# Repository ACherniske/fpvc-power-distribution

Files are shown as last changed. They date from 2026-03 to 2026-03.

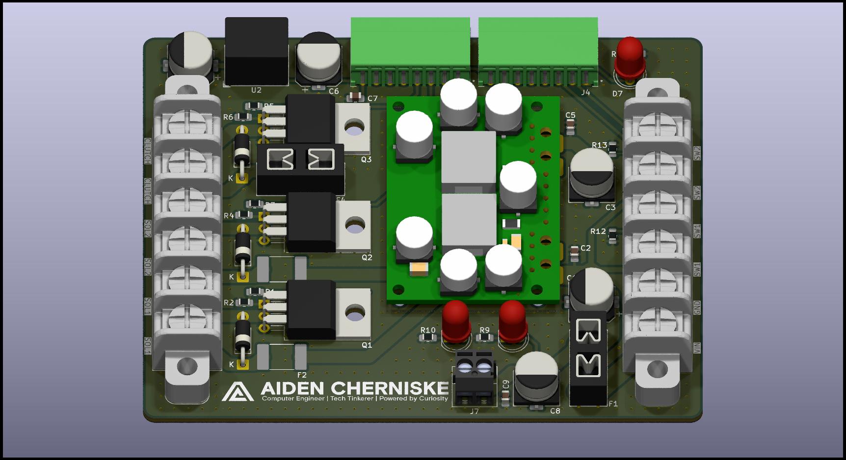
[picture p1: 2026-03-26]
images/fpvc-power-distribution.jpg

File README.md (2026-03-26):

# FPVC Power Distribution Board







A 2-layer power distribution board designed in KiCad for the NFPA Fluid Powered Vehicle Challenge. Handles input fusing, load switching via MOSFETs, and regulated 5V/12V/24V outputs.

---

## Board Images

### Top and bottom layers

| Top layer | Bottom layer |
|---|---|
| FPVC power distribution board top layer | FPVC power distribution board bottom layer |

### Schematic

FPVC power distribution board overview

---

## Ordering from JLCPCB

### 1. Download the Gerber files

Download the latest Gerber files from the [Releases](../../releases) page as a `.zip` file. Do not unzip it — JLCPCB accepts the zip directly.

### 2. Upload to JLCPCB

1. Go to [jlcpcb.com](https://jlcpcb.com) and click **Order Now**
2. Click **Add Gerber File** and upload the `.zip`
3. JLCPCB will render a preview of the board — verify it looks correct before continuing

### 3. Configure the order options

Once uploaded, a list of fabrication options will appear. Set them as follows:

| Option | Value | Notes |
|---|---|---|
| **Base Material** | FR-4 | Standard PCB material |
| **Layers** | 2 | |
| **Dimensions** | Auto-detected | Verify against preview |
| **PCB Qty** | 5 (minimum) | Adjust as needed |
| **PCB Thickness** | 1.6mm | Standard |
| **PCB Color** | Your choice | Green is cheapest/fastest |
| **Silkscreen** | White | |
| **Surface Finish** | HASL (with lead) | Lead-free HASL also fine |
| **⚠️ Outer Copper Weight** | **2oz** | **Critical — must change from default** |
| **Via Covering** | Tented | |
| **Board Outline Tolerance** | ±0.2mm | Standard |
| **Confirm Production File** | No | |
| **Remove Order Number** | No | Yes adds ~$1.50 |

> **Why 2oz copper?** This board carries significant DC load currents through its power traces. 2oz copper (70µm) doubles the trace cross-sectional area compared to the default 1oz, reducing resistance and heat buildup. **Do not order with 1oz copper.**

### 4. Shipping & checkout

1. Click **Save to Cart**
2. Select your shipping method — **DHL Express** or **FedEx** typically arrive in 5–7 days to the US. Economy options are cheaper but can take 3–5 weeks
3. Complete checkout and pay

JLCPCB will send an email when the order moves to production and again when it ships.

---

## Bill of Materials

See [`fpvc-power-distribution-BOM.xlsx`](./documentation/fpvc-power-distribution-BOM.xlsx) for the full BOM. There is a mix of through-hole and surface-mount components. The 0805 package is hand-solderable or can be reflowed.

DigiKey links are provided in the BOM for all components that cannot be found in the Bucknell Maker-E Makerstock.

---

## License

Copyright 2026 Aiden Cherniske

Licensed under the Apache License, Version 2.0. See [`LICENSE`](./LICENSE) for the full text.

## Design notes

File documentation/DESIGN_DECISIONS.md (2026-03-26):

# PCB Design Decisions & Rationale

> Power distribution board designed for the Fluid Powered Vehicle Challenge Senior Design project at Bucknell Unviersity. PCB interfaces with the Velocio Ace PLC to enable the powering and switching of essential bike systems.

---

## Contents

- [Copper Weight](#copper-weight)
- [Trace Width Safety Margins](#trace-width-safety-margins)
- [Ground Planes](#ground-planes)
- [Via Sizing & Parallelism](#via-sizing--parallelism)
- [2-Layer vs 4-Layer](#2-layer-vs-4-layer)

---

## Copper Weight

**Decision:** 2oz copper (70µm) throughout both layers.

2oz was chosen over the standard 1oz, providing roughly double the current carrying capacity per unit trace width. This allows narrower traces for the same current rating and is particularly important for the high current 24V input and clutch circuits, where 1oz copper would require impractically wide traces.

---
 
## Trace Width Safety Margins
 
**Decision:** ~50% margin added over IPC-2221 calculated minimums.
 
All trace widths were calculated using the IPC-2221 standard with the following assumptions:
 
| Parameter | Value |
|---|---|
| Copper weight | 2oz |
| Max temperature rise | 20°C |
| Worst case ambient | 50°C |
| Max conductor temperature | 70°C |
 
The 50% margin accounts for manufacturing variation, hot spots at vias and corners, and transient currents from inductive switching.
 
| Net | IPC-2221 minimum | Routed width |
|-----|---|---|
| Signal / gate drive | 0.1mm | 0.2mm |
| +5V rail | 0.2mm | 0.5mm |
| +12V solenoids (4A total) | 0.6mm | 1.0mm |
| +12V clutch (8A) | 1.8mm | 2.5mm |
| 24V input (15A) | 3.5mm | 4.0mm |

---
 
## Ground Planes
 
**Decision:** GND pours are used on both top and bottom layers.
 
Rather than routing individual signal returns, both copper layers include ground pours tied to the same GND net. This provides low-impedance return paths near active routing on each layer, minimises loop area, and improves current sharing for high-current returns (clutch and solenoid circuits) without requiring oversized dedicated return traces.
 
Stitching vias are used to tie the two GND pours together and prevent isolated copper islands. They are arranged in a 2.54mm grid for regular stitching in open copper regions.

---
 
## Via Sizing & Parallelism
 
**Decision:** Vias are sized by function, with multiple vias in parallel for power nets and a dedicated stitching-via setup for GND pours.
 
Rather than a single standard via size, three classes are used:
 
| Via type | Drill | Finished diameter | Parallelism |
|---|---|---|---|
| Signal | 0.3mm | 0.7mm | Single |
| Power (5V, 12V) | 0.4mm | 0.8mm | 2–3 in parallel |
| High current (24V, clutch) | 0.6mm | 1.2mm | 4–6 in parallel |
| GND stitching | 0.3mm | 0.6mm | 2.54mm grid + additional vias at edges and return-layer transitions |
 
Parallel vias distribute current across multiple paths and provide redundancy against manufacturing defects in any single via.

For GND stitching, KiCad fill-area settings are 0.6mm via diameter, 0.3mm drill, 0.2mm clearance, and 2.54mm grid spacing.

---
 
## Decoupling Capacitor Placement
 
**Decision:** Two-stage decoupling per rail, with strict placement order.
 
Each power rail uses two capacitors placed in sequence along the power trace:
 
```
Connector → 100µF electrolytic → 100nF ceramic → IC power pin
```

- The **100nF ceramic** is placed as close as physically possible to the IC power pin to suppress high frequency noise. Its GND via is placed directly at the pad — not routed to a distant ground point.
- The **100µF electrolytic** is placed further back as a bulk charge reservoir for low frequency ripple.

---
 
## Fuse Strategy
 
**Decision:** SMD polyfuses for low current circuits, Mini blade fuses for high current circuits.
 
| Circuit | Fuse type | Reason |
|---|---|---|
| Solenoids (2A each) | SMD polyfuse, 2920 package | Self-resetting, appropriate for low current inductive loads |
| Clutch (7.5A) | Mini blade, PCB-mount holder | Polyfuses impractical at this current level |
| 24V input (15A) | Mini blade, PCB-mount holder | Polyfuses impractical at this current level |
 
At 7A and above, polyfuses have high hold resistance causing significant voltage drop, are difficult to source, and are expensive. Mini blade fuses are universally available at any automotive supplier, making field replacement straightforward without specialist parts.

---

## 2-Layer vs 4-Layer
 
**Decision:** 2-layer board.
 
The signal frequencies in this design are very low — PLC digital I/O, MOSFET switching for solenoids and a clutch, and DC power regulation. There are no high frequency switching converters, differential signal pairs, or RF circuits that would benefit from the additional ground plane isolation that 4-layer construction provides.
 
4-layer construction often increases PCB fabrication cost. If EMI issues are identified during testing, a 4-layer revision would be straightforward, but this is not anticipated given the low frequency nature of the design.

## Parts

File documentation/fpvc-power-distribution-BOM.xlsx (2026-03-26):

FPVC Power Distribution — Bill of Materials
Qty | Designator | Val | Footprint | Link
5 | R2,R13,R4,R12,R6 | 10k | R_0805_2012Metric_Pad1.20x1.40mm_HandSolder | Maker-E Components
3 | D3,D1,D2 | 1N5819 | D_DO-41_SOD81_P10.16mm_Horizontal | https://www.digikey.com/en/products/detail/stmicroelectronics/1N5819/1865421
2 | F1, F4 | Various | Fuseholder_Blade_Mini_Keystone_3568 | https://www.digikey.com/en/products/detail/keystone-electronics/3568/2137306
1 | F1 | 15A | Mini Blade Fuse | https://www.digikey.com/en/products/detail/littelfuse-inc/0MIN015-VP/3426493
1 | F4 | 7.5A | Mini Blade Fuse | https://www.digikey.com/en/products/detail/littelfuse-inc/029707-5WXNV/146586
5 | C4,C6,C3,C1,C8 | 100uF | CP_Elec_8x6.2 | https://www.digikey.com/en/products/detail/vishay-beyschlag-draloric-bc-components/MAL215097011E3/5635404
3 | Q3,Q1,Q2 | IRLB8314 | TO-220-3_Horizontal_TabDown | https://stock.maker.bucknell.edu/product/nmos-through-hole-3-3v-gate/
4 | C5,C2,C9,C7 | 0.1uF | C_0805_2012Metric_Pad1.18x1.45mm_HandSolder | Maker-E Components
1 | R9 | 2.2k | R_0805_2012Metric_Pad1.20x1.40mm_HandSolder | Maker-E Components
3 | D5, D6, D7 | Various | LED_D5.0mm | https://stock.maker.bucknell.edu/product/led-red-2/
3 | R3,R5,R1 | 220 | R_0805_2012Metric_Pad1.20x1.40mm_HandSolder | Maker-E Components
1 | R11 | 200 | R_0805_2012Metric_Pad1.20x1.40mm_HandSolder | Maker-E Components
2 | F3,F2 | 2A Polyfuse | Fuse_2920_7451Metric_Pad2.10x5.45mm_HandSolder | https://www.digikey.com/en/products/detail/bourns-inc/MF-LSMF200-24X-2/16053096
1 | R10 | 1k | R_0805_2012Metric_Pad1.20x1.40mm_HandSolder | Maker-E Components
1 | U2 | R-78K 5.0-1.0 | Converter_DCDC_RECOM_R-78E-0.5_THT | https://stock.maker.bucknell.edu/product/dc-dc-converter-5-v-1-a/
1 | J7 | Vout_Screen | TerminalBlock_4Ucon_1x02_P3.50mm_Vertical | https://stock.maker.bucknell.edu/product/terminal-blocks-2/
2 | J4, J5 | Various | PHOENIX_1881503 | https://www.digikey.com/en/products/detail/phoenix-contact/1881503/308252
2 | J4, J5 | Various | PHOENIX_1881383 | https://www.digikey.com/en/products/detail/phoenix-contact/1881383/308241
2 | J9, J10 | Various | 8.26mm Pitch Beau PCB Terminal Strip | https://www.digikey.in/en/products/detail/molex/0387006106/3315660

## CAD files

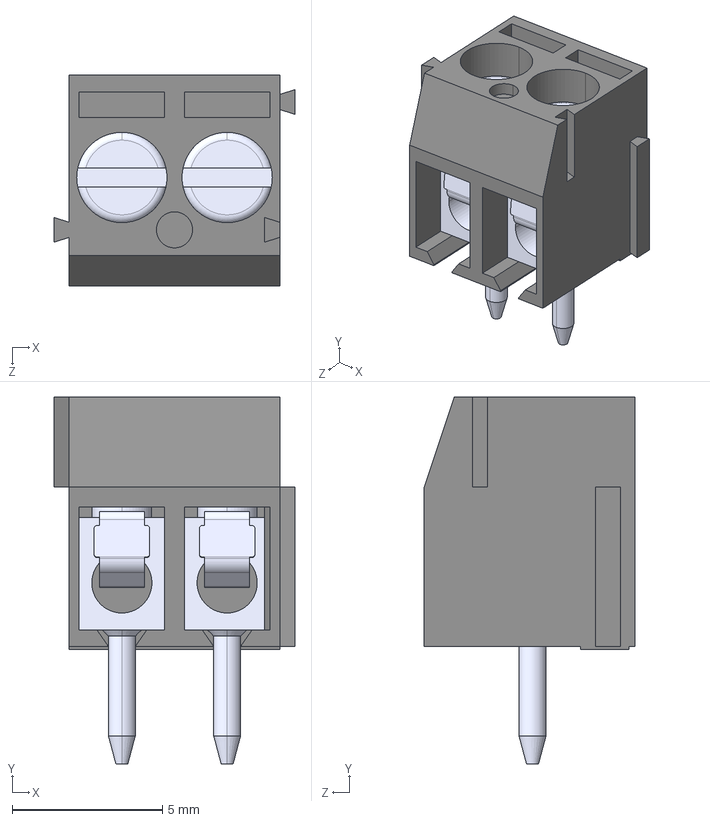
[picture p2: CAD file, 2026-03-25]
kicad/models/OSTTE020104.STEP
8.00 x 12.2 x 7.00 mm

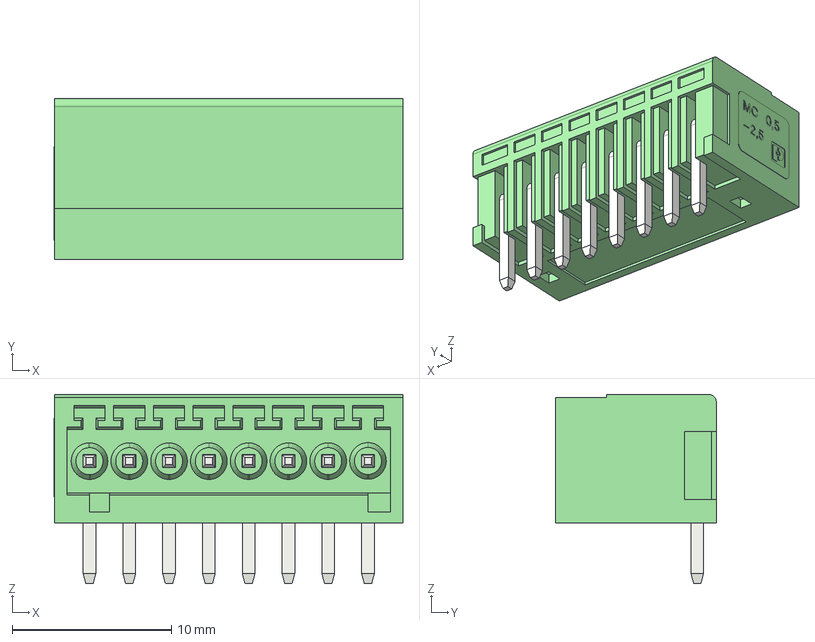
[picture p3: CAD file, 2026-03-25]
kicad/models/pxc_1881503_00_02_MC-0-5-8-G-2-5_3D.stp
21.9 x 10.1 x 11.9 mm

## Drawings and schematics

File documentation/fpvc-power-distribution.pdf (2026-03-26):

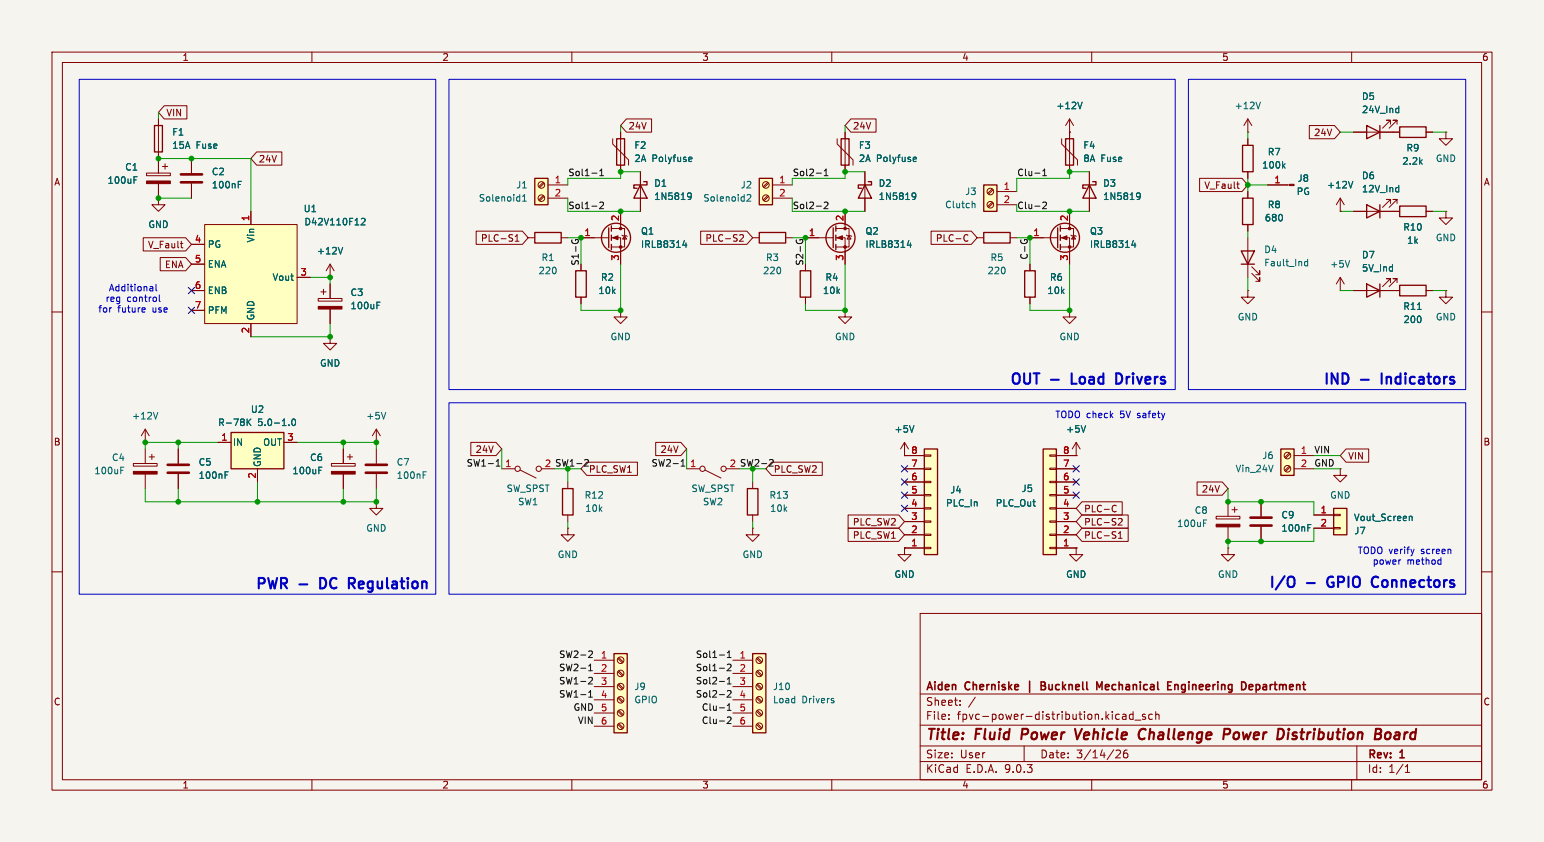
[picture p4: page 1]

Additional reg control for future use

Id: 1/1 Title: Fluid Power Vehicle Challenge Power Distribution Board

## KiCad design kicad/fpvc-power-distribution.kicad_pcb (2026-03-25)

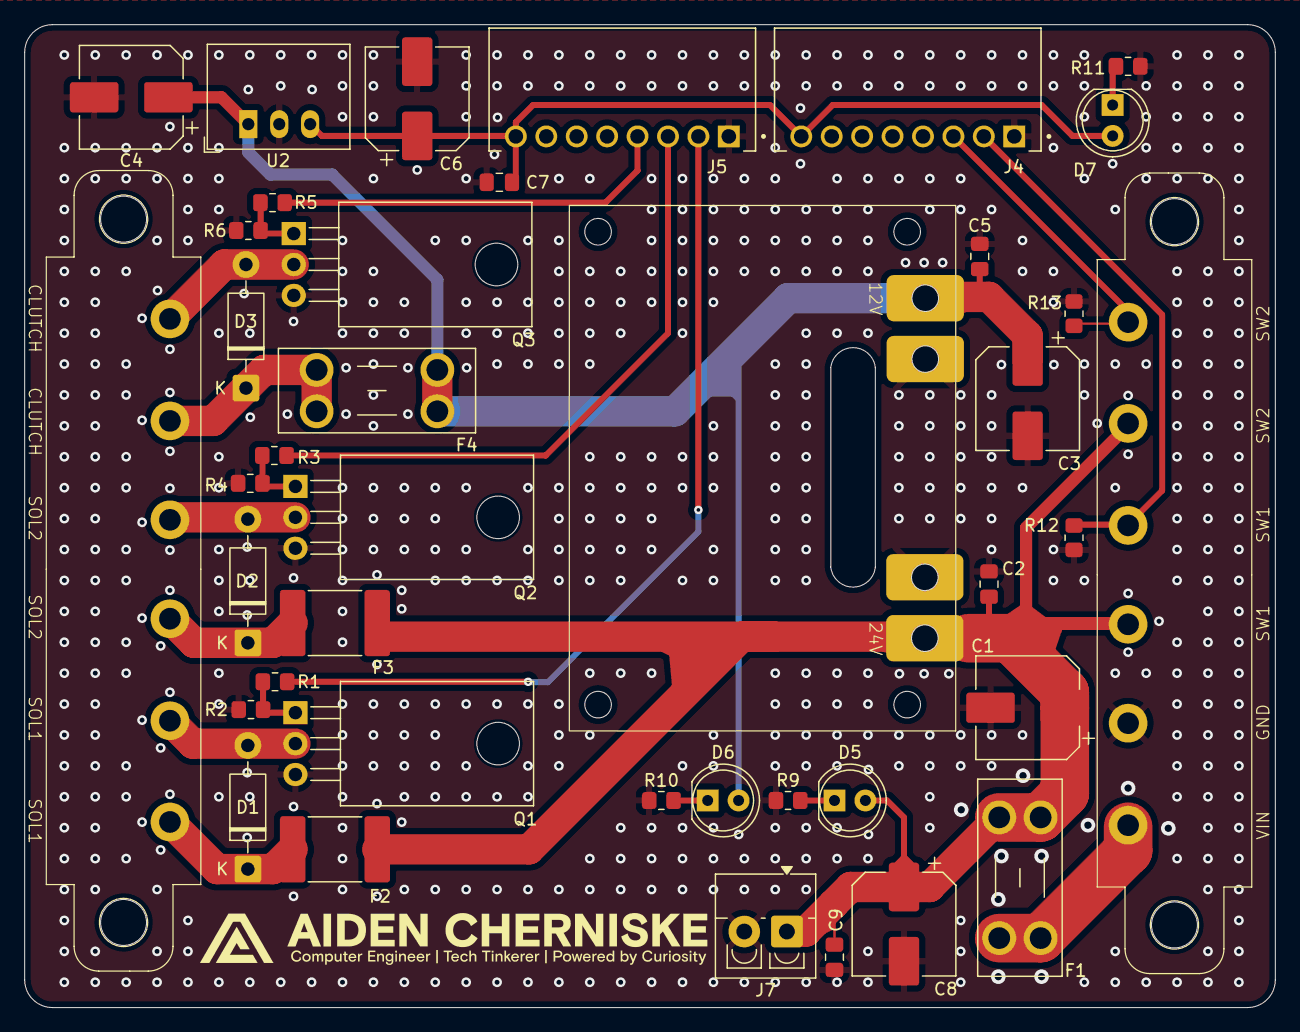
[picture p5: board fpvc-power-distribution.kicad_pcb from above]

Board: 2 copper layers, 102.8 x 80.8 mm, 40 parts (0 on the bottom side), 22 nets.

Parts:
C1, C3, C4, C6, C8: 100uF; CP_Elec_8x6.2
C2, C5, C7, C9: 100nF; C_0805_2012Metric_Pad1.18x1.45mm_HandSolder
D1, D2, D3: 1N5819; D_DO-41_SOD81_P10.16mm_Horizontal
D5: 24V_Ind; LED_D5.0mm
D6: 12V_Ind; LED_D5.0mm
D7: 5V_Ind; LED_D5.0mm
F1: 15A Fuse; Fuseholder_Blade_Mini_Keystone_3568
F2, F3: 2A Polyfuse; Fuse_2920_7451Metric_Pad2.10x5.45mm_HandSolder
F4: 8A Fuse; Fuseholder_Blade_Mini_Keystone_3568
J4: PLC_In; PHOENIX_1881503
J5: PLC_Out; PHOENIX_1881503
J7: Vout_Screen; TerminalBlock_4Ucon_1x02_P3.50mm_Vertical
J9: GPIO; 8.26mm Pitch Beau PCB Terminal Strip
J10: Load Drivers; 8.26mm Pitch Beau PCB Terminal Strip
Q1, Q2, Q3: IRLB8314; TO-220-3_Horizontal_TabDown
R1, R3, R5: 220; R_0805_2012Metric_Pad1.20x1.40mm_HandSolder
R2, R4, R6, R12, R13: 10k; R_0805_2012Metric_Pad1.20x1.40mm_HandSolder
R9: 2.2k; R_0805_2012Metric_Pad1.20x1.40mm_HandSolder
R10: 1k; R_0805_2012Metric_Pad1.20x1.40mm_HandSolder
R11: 200; R_0805_2012Metric_Pad1.20x1.40mm_HandSolder
U1: D42V110F12
U2: R-78K 5.0-1.0; Converter_DCDC_RECOM_R-78E-0.5_THT

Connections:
24V: C1.1, C2.1, C8.1, C9.1, D5.2 (A), F1.2, F2.1, F3.1, J7.1, J9.2, J9.4, U1.1 (Vin)
+5V: C6.1, C7.1, D7.2 (A), J4.8, J5.8, U2.3 (OUT)
+12V: C3.1, C4.1, C5.1, D6.2 (A), F4.1, U1.3 (Vout), U2.1 (IN)
/C-G: Q3.1 (G), R5.2, R6.1
/Clu-1: D3.1 (K), F4.2, J10.5
/Clu-2: D3.2 (A), J10.6, Q3.2 (D)
/S1-G: Q1.1 (G), R1.2, R2.1
/S2-G: Q2.1 (G), R3.2, R4.1
/Sol1-1: D1.1 (K), F2.2, J10.1
/Sol1-2: D1.2 (A), J10.2, Q1.2 (D)
/Sol2-1: D2.1 (K), F3.2, J10.3
/Sol2-2: D2.2 (A), J10.4, Q2.2 (D)
GND: C1.2, C2.2, C3.2, C4.2, C5.2, C6.2, C7.2, C8.2, C9.2, J4.1, J5.1, J7.2, J9.5, Q1.3 (S), Q2.3 (S), Q3.3 (S), R2.2, R4.2, R6.2, R9.1, R10.1, R11.1, R12.2, R13.2, U1.2 (GND), U2.2 (GND)
unnamed: D5.1 (K), R9.2
unnamed: D6.1 (K), R10.2
unnamed: D7.1 (K), R11.2
PLC-C: J5.4, R5.1
PLC-S1: J5.2, R1.1
PLC-S2: J5.3, R3.1
PLC_SW1: J4.2, J9.3, R12.1
PLC_SW2: J4.3, J9.1, R13.1
VIN: F1.1, J9.6

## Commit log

2026-03-15 chore: Create kicad 9 project
    [fpvc-power-distribution.kicad_pcb, fpvc-power-distribution.kicad_sch]
2026-03-15 feat: Plan mosfet based solenoid and clutch actuation
    [fpvc-power-distribution.kicad_sch]
2026-03-15 feat: Create voltage regulator symbol and schematic
    [fpvc-power-distribution.kicad_sch]
2026-03-15 feat: Add proper regulator fault detection and power indication
    [fpvc-power-distribution.kicad_sch]
2026-03-19 feat: Add 5V DC/DC converter for PLC
    [fpvc-power-distribution.kicad_sch]
2026-03-19 style: Clean up schematic and add labels
    [fpvc-power-distribution.kicad_sch]
2026-03-19 style: Complete schematic formatting
    [fpvc-power-distribution.kicad_sch]
2026-03-24 feat: Update schematic with GPIO connectors
    [fpvc-power-distribution.kicad_sch]
2026-03-24 fix: Add decoupling caps to screen power connector
    [fpvc-power-distribution.kicad_sch]
2026-03-24 style: Fix formatting in I/O section
    [fpvc-power-distribution.kicad_sch]
2026-03-24 feat: Add custom footprints
2026-03-24 feat: Fix annotations and footprint assignments
    [fpvc-power-distribution.kicad_sch]
2026-03-24 feat: Finish PCB revision 1
    [fpvc-power-distribution.kicad_pcb, fpvc-power-distribution.kicad_sch]
2026-03-24 feat: Generate stitching vias
    [fpvc-power-distribution.kicad_pcb]
2026-03-24 fix: Correct 24V trace angle
    [fpvc-power-distribution.kicad_pcb]
2026-03-24 feat: Update silkscreen
    [fpvc-power-distribution.kicad_pcb]
2026-03-25 feat: Update 3d models
    [fpvc-power-distribution.kicad_pcb, pxc_1881503_00_02_MC-0-5-8-G-2-5_3D.stp]
2026-03-25 fix: Replace 2.54mm pitch pin header with 3.5mm terminal block for screen power connections
    [OSTTE020104.STEP, fpvc-power-distribution.kicad_pcb]
2026-03-25 style: Update pcb editor information and clean up file
    [fpvc-power-distribution.kicad_pcb]
2026-03-26 feat: Add BOM with digikey links and makerstock components
    [fpvc-power-distribution-BOM.xlsx]
2026-03-26 feat: Generate fabrication outputs
    [fpvc-power-distribution-B_Cu.gbr, fpvc-power-distribution-B_Mask.gbr, fpvc-power-distribution-B_Paste.gbr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]
2026-03-26 docs: Remove D42V110F12 Voltage Regulator Pin Summary documentation
2026-03-26 docs: Add DESIGN_DECISIONS.md with PCB design rationale and decisions
2026-03-26 docs: Update net_colors and plot_directory in KiCad project file
2026-03-26 docs: Add schematic and pcb images
2026-03-26 docs: Add board images and schematic to README
2026-03-26 docs: Add power distribution schematic PDF to documentation

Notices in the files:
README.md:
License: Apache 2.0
